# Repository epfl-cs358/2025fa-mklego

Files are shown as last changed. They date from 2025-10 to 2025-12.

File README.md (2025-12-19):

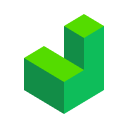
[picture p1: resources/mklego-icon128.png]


# CS-358 Project : MKLEGO 

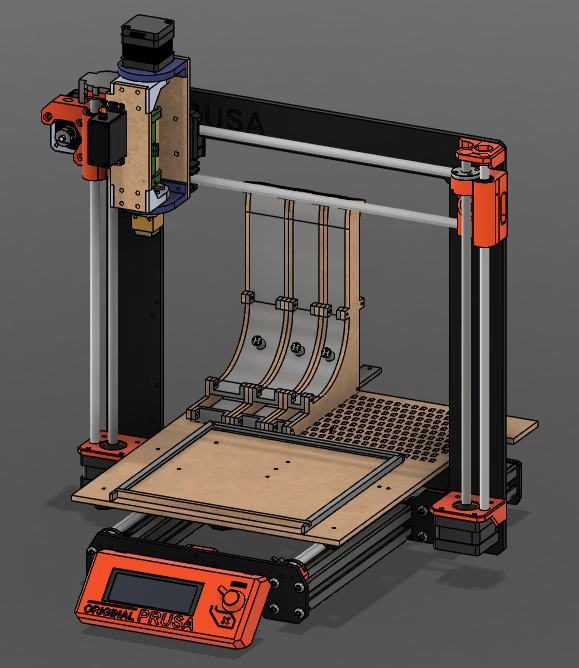
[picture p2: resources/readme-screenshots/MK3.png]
 

## Project overview

MKLEGO is a 3D printer that uses LEGO bricks to build any given structure layer by layer. The project is based on mofifying a PRUSA MK3 3D printer by 
- replacing the extruder with a custom nozzle that can pick, place and rotate LEGO bricks,
- changing the base plate to a LEGO compatible plate with place for custom LEGO brick dispensers,
- developing custom software to convert 3D models into LEGO brick instructions.

## Software
### How to run
Access the software repository here: [MKLEGO Software](/frontend/).
Run it by :
- From the `frontend` folder, run the project with 
   
   `./gradlew :desktop-app:run`.
- The application window should open. You can see your recent projects and open them if there are any.

Creating a new project :
- To create a new project, click on File > New File, then select an STL or lxfml file to load and slice a 3D model, or nothing to create a blank project.
- You can go back to the recent projects by clicking on File > Recent Projects.

Editing :
- Once you have opened a project, you can add, remove, or paint LEGO bricks.
- You can see the controls by pressing `H`.
- To paint an existing brick: select the targeted brick, then click on a color in the palette.
- Note: you can only place blocks on top of other blocks. You cannot add a floating brick

Supports :
- The translucid bricks are support bricks. They are added automatically underneath hanging bricks. You can also add some manually by using the gray color (rightmost) in the color palette. You can hide/show them by clicking on "Hide Supports" in the top right.

Printing :
- To export your LEGO project: open the desired project and go to File > Export as ... : use lgcode for human readable gcode, or LG for the binary file.
- To print your LEGO structure, export it as LG, store it in a SD card and transfer the file to the printer. Then, you can set the printer and launch the build through the printer's screen interface.
- You will be asked to show on the screen where your dispensers are placed and then the real printing will begin!

Screen Interface:
- Home Screen: you can select to either go to print or to settings
- Settings: Calibrate: Calibrate the x, y, z axis and the rotation (will automatically be done at the beginning of each print), Back: Get back to main menu (Home)
- Print menu: Press Files to choose a file to execute and Back to get back to Home. If on files choose which file to execute.
- File execution: If .TXT file the screen will play a music corresponding to the file. If .LG or .LGCODE file the model will be printed

### Pipeline
The JavaFX-based software pipeline includes:
- Loading a 3D model from an STL or lxfml (v5.0 Legacy LDD compatible) file,
- Slicing it into LEGO brick layers and assembling them in an optimal agencement,
- Rendering the LEGO structure in a 3D viewer to view and edit the build if needed,
- Generating the lgcode (custom g-code) instructions to be sent to the printer.

## Hardware architecture
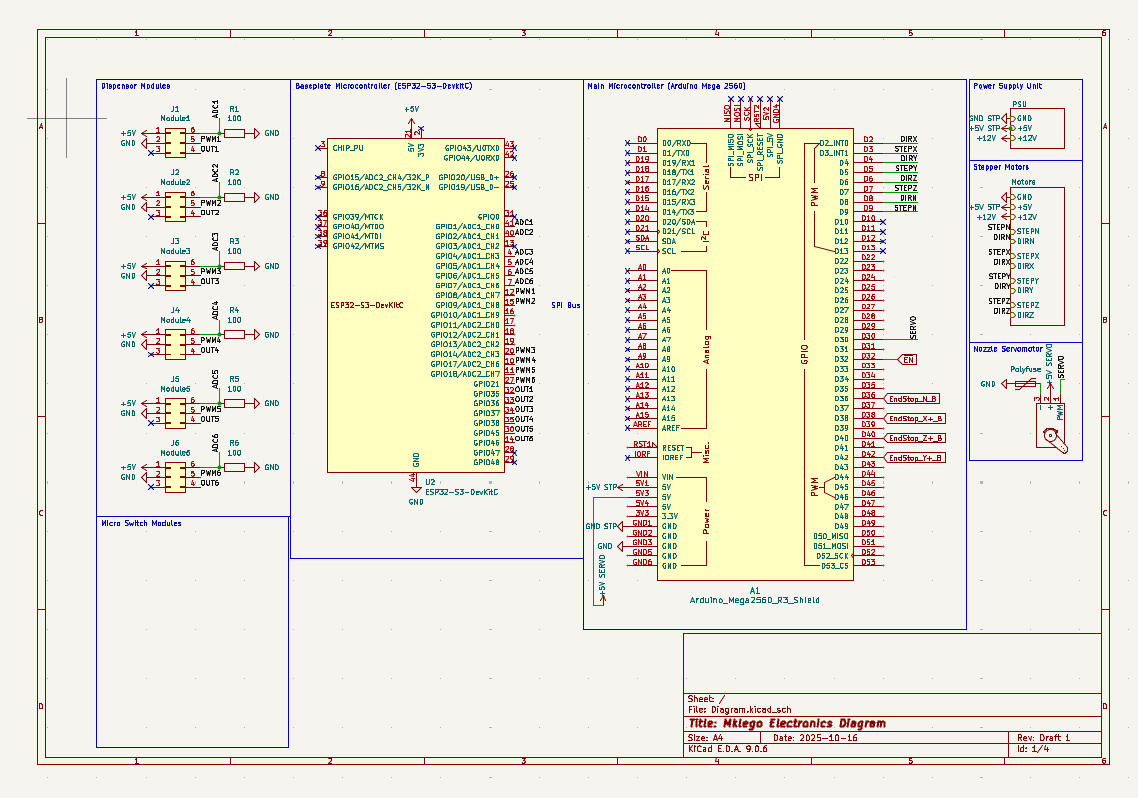
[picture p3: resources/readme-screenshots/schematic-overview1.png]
 
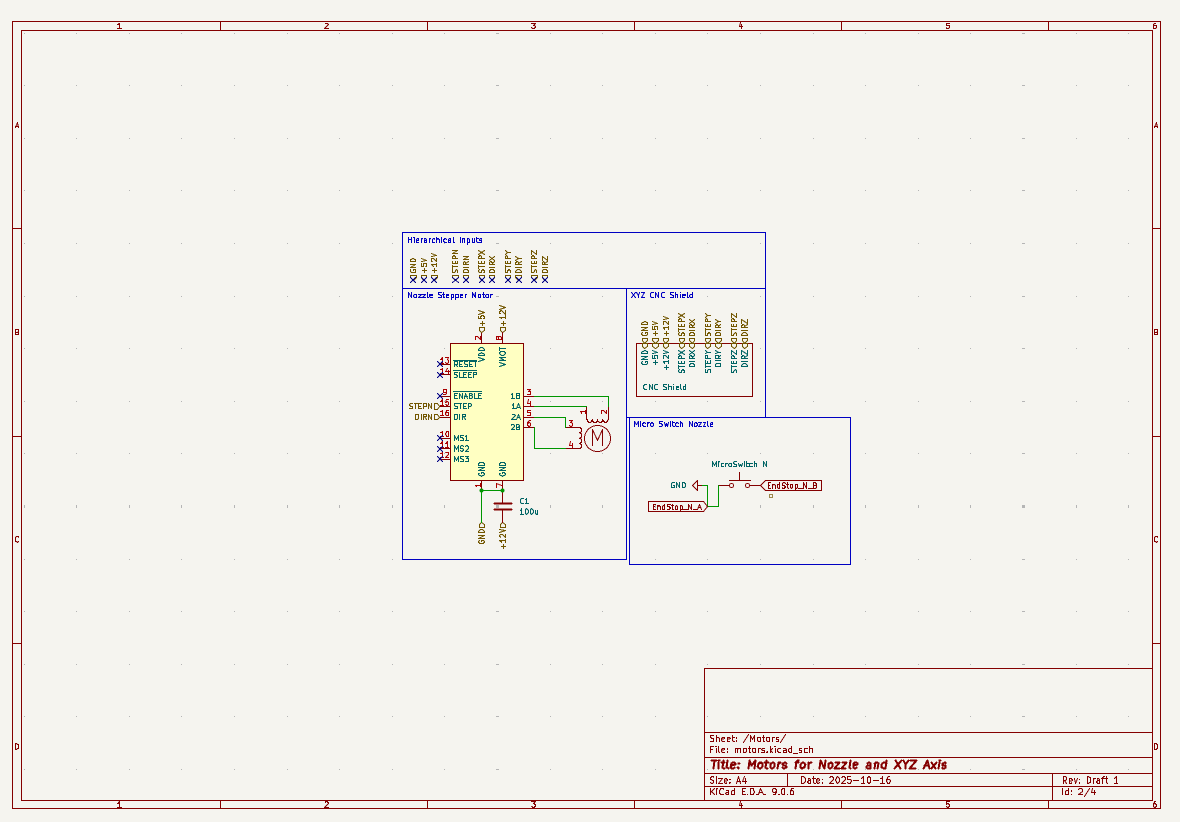
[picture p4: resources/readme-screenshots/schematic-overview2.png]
 
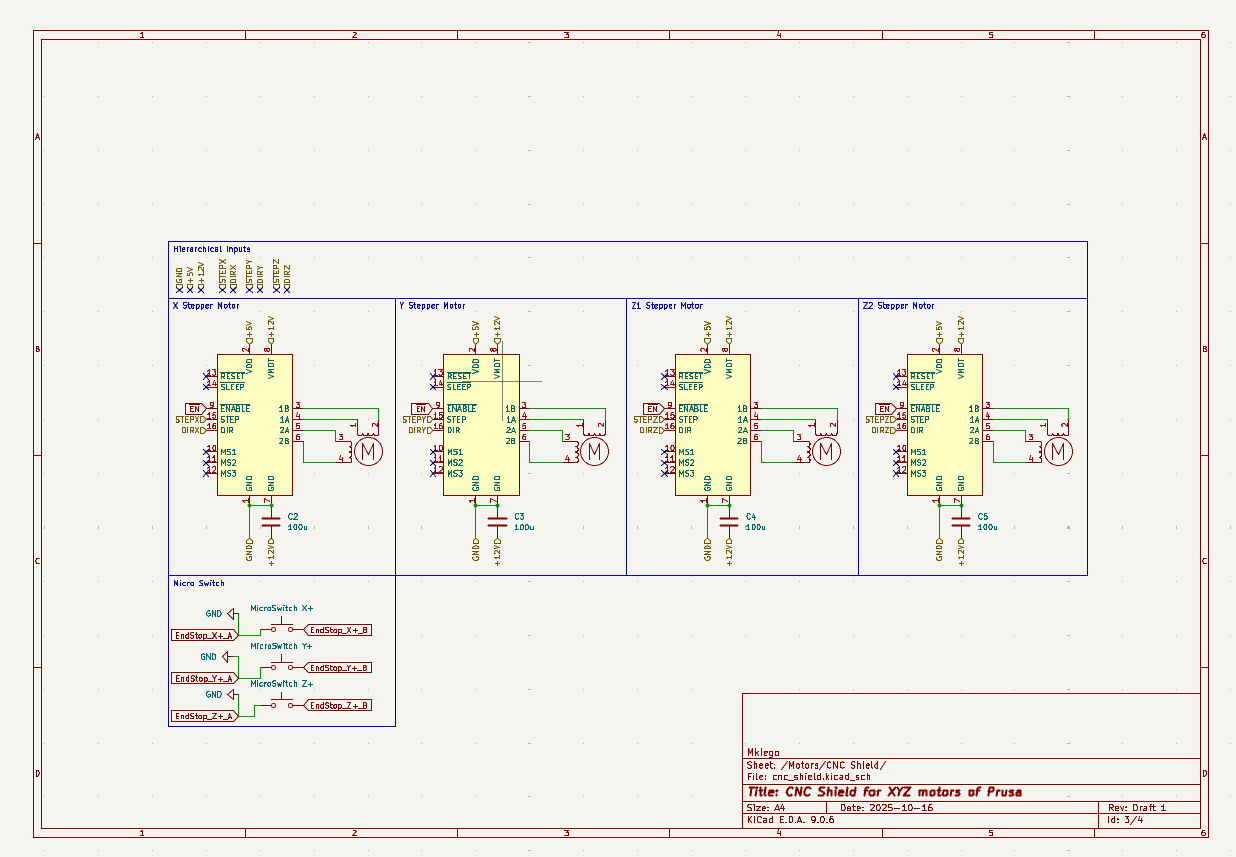
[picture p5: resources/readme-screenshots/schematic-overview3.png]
 

### Firmware
Access the firmware repository here: [MKLEGO Firmware](/embedded/mklego).

### System Overview

The hardware is organized around a **dual-microcontroller architecture**:

- **Main Controller**: Arduino Mega 
  Responsible for motion control (stepper motors), safety-critical timing, and real-time coordination.

- **Baseplate Controller**: ESP32-S3-DevKitC  
  Responsible for high-level logic, sensor acquisition, dispenser module control, and communication with the main controller.

The system integrates:
- Up to **8 LEGO dispenser modules**
- **3-axis stepper motor control (X, Y, Z)**
- A **servo motor** that pushes the brick down through the nozzle
- A centralized **power supply unit (PSU)** providing 5 V and 12 V rails

# Building Tutorial

This section explains how to physically build the MKLEGO prototype from a Prusa MK3 printer and the provided custom parts.  
All mechanical parts (DXF, STL and 3MF files) are available in the repository.

---

## Step 1: Preparation

### Required base machine
This prototype **requires a Prusa MK3 printer** as the mechanical base (frame, linear rails, motors).

### Disassembly
Before starting the build:

1. Power off and unplug the printer.
2. Remove the following components from the Prusa MK3:
   - Heated bed
   - Original extruder and hotend
   - Power Supply Unit (PSU)

⚠️ These components are **not used** in the MKLEGO system.

At the end of this step, you should keep:
- The printer frame
- X/Y/Z motion system
- Stepper motors

---

## Step 2: Mechanical Assembly Overview

The MKLEGO hardware is composed of three main subsystems:

1. **Custom LEGO Nozzle**
2. **LEGO-Compatible Base Plate**
3. **LEGO Brick Dispensers**

Each subsystem can be assembled independently before final integration on the printer.

---

## Nozzle Assembly

<p align="center">
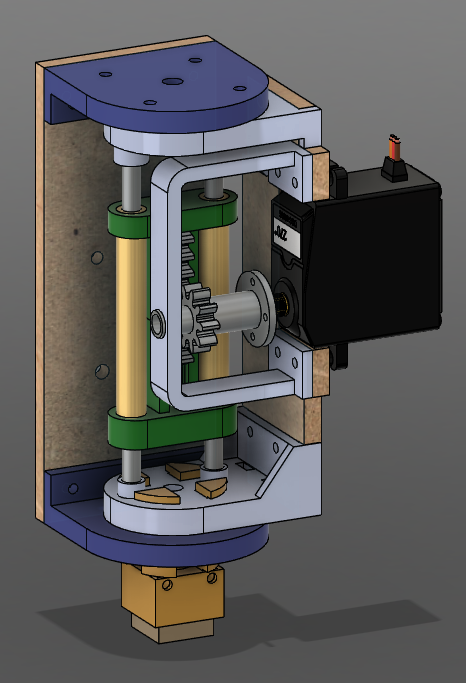
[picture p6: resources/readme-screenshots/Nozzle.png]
  
</p>
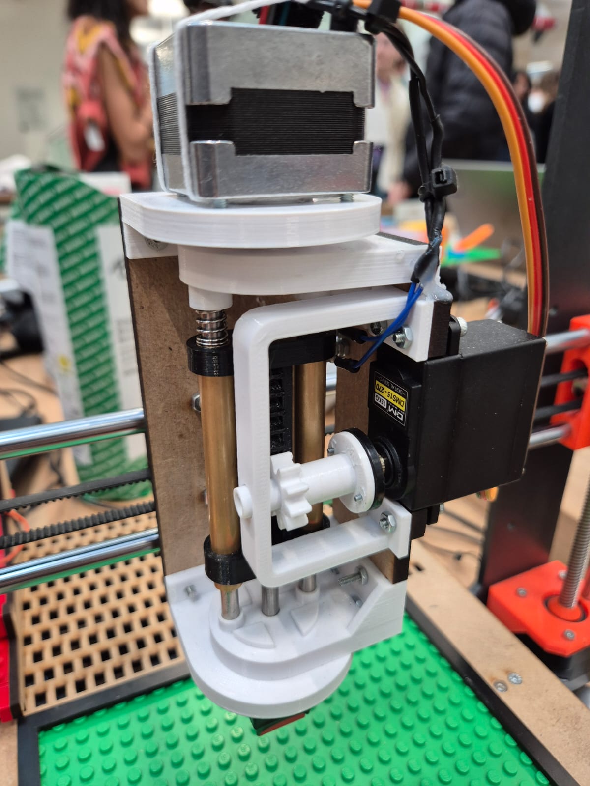
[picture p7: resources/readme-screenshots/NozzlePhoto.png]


### Notes
Primarily use M3 screws. M2.5 depending on the 3d files

---

### Materials

- [ ] 1 × NEMA 14 stepper motor  
- [ ] 1 × Servo motor (15 kg·cm recommended)  
- [ ] 2 × Brass hollow cylinders  
  - Outer diameter: 8 mm  
  - Inner diameter: 5 mm  
  - Length: 64 mm  
- [ ] 2 × Metal rods (97 mm long)  
- [ ] 3 × Springs (10 mm length)  
- [ ] 1 × Micro-switch  
- [ ] M3 and M2.5 screws and nuts  
- [ ] MDF parts (laser cut)  
- [ ] PETG parts (3D printed)

---

### Assembly Process

1. **Prepare the parts**
   - Find all the files in the resources/3D Models folder.
   - Laser cut all MDF components using the provided DXF files.
   - 3D print all plastic parts using the provided STL files (PETG).

3. **Linear structure**
   - Assemble all sliding components along the two metal rods.
   - Ensure smooth motion without excessive friction.

4. **Rotation mechanism**
   - Mount the servo motor.
   - Assemble the rotating LEGO-gripping section.
   - Don't forget the 2 springs: They go between the sliding part and the rotating part on the 2 outer rods.

5. **Final enclosure**
   - Add the fixed (non-rotating) outer structure.
   - Add the Lego grabber at the bottom. Don't forget the spring right above the grabber, on the rod.
   - Install the micro-switch for rotation calibration.

A fully assembled 3D model of the nozzle is available as a **3MF file** for reference.

### Notes:
Use M3 conical screws to connect the baseplate to the printer

---

## Base Plate Assembly

<p align="center">
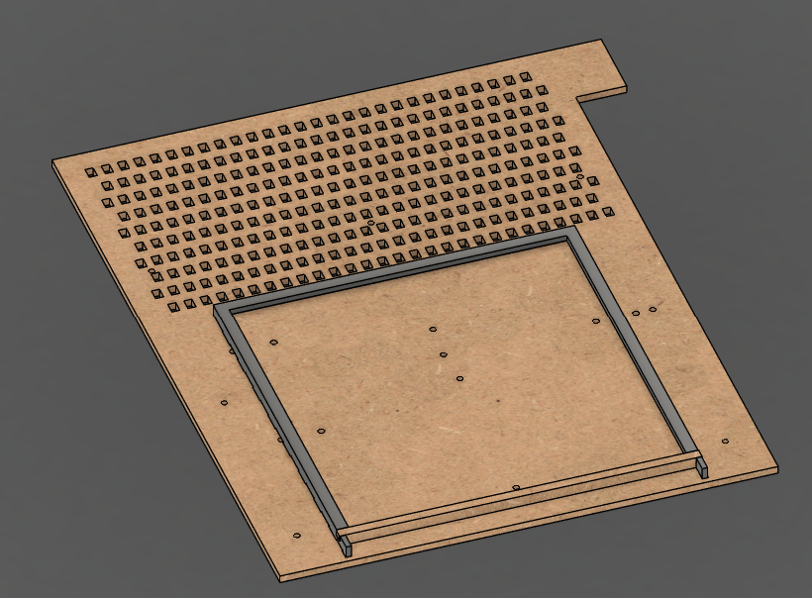
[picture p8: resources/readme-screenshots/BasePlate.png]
  
</p>

---

### Materials

- [ ] 1 × Micro-switch  
- [ ] MDF parts (laser cut)  
- [ ] PETG parts (3D printed)  
- [ ] 1 × LEGO base plate (22 × 22 studs)

---

### Assembly Process

1. Fabricate all MDF and PETG parts using the provided DXF and STL files in resources/3D Models/.
2. Assemble the mechanical structure of the base plate.
3. Install the micro-switch for Y-height referencing.
4. **You do not need mount the LEGO plate yet**

### Notes:
Use M3 conical screws to connect the dispensers as there needs to not be anything between them
do not add any screws to the middle screw holes of the dispensers
The path to lay the wires on the left side of the dispenser needs to be filed down to fit two wires 

A complete assembled model is also available as a **3MF file**.   

---

## Dispenser Assembly

<p align="center">
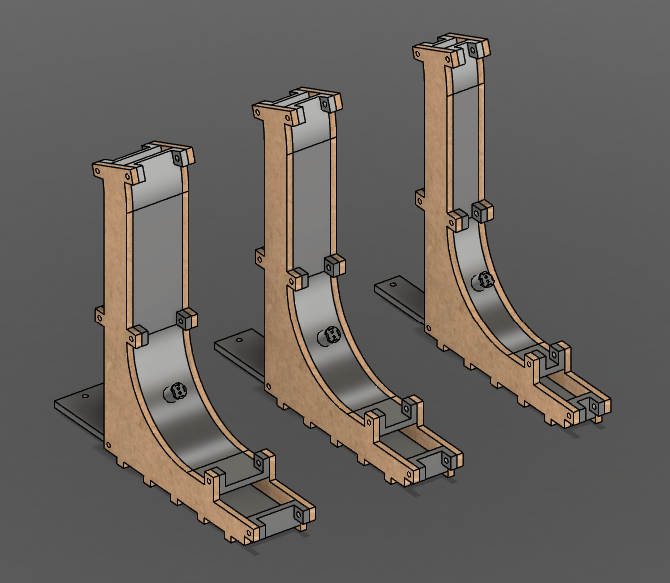
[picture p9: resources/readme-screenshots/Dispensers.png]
  
</p>

---

### Materials (per dispenser)

- [ ] 1 × IR LED  
- [ ] 1 × IR Receiver  
- [ ] M3 screws and nuts  
- [ ] MDF parts (laser cut)  
- [ ] PETG parts (3D printed)

---

### Assembly Process

1. Assemble the mechanical ramp structure. (Find all the files to make the parts in resources/3D Models/)
2. Install the IR LED and IR receiver:
   - Align them carefully to ensure reliable brick detection.
3. Test brick feeding manually before electronic integration.

A complete dispenser assembly is provided as a **3MF file**.

---
## Micro switches
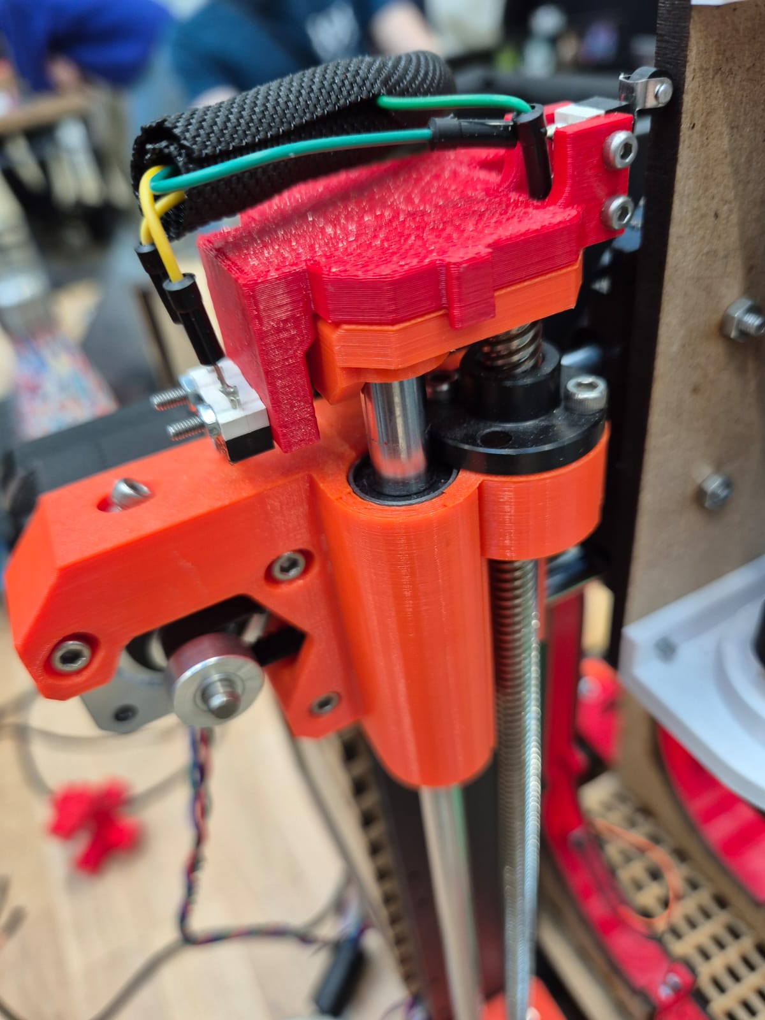
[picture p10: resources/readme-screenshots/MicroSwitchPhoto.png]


--- 

### Materials

- [ ] M2.5 screws and bolts
- [ ] 2 micro switches
- [ ] wires
- [ ] PETG parts (3D printed)

### Assembly Process
- Find the files in resources/3D Models
- Print the 3D structure
- Connect the wires into the main electrical box

---
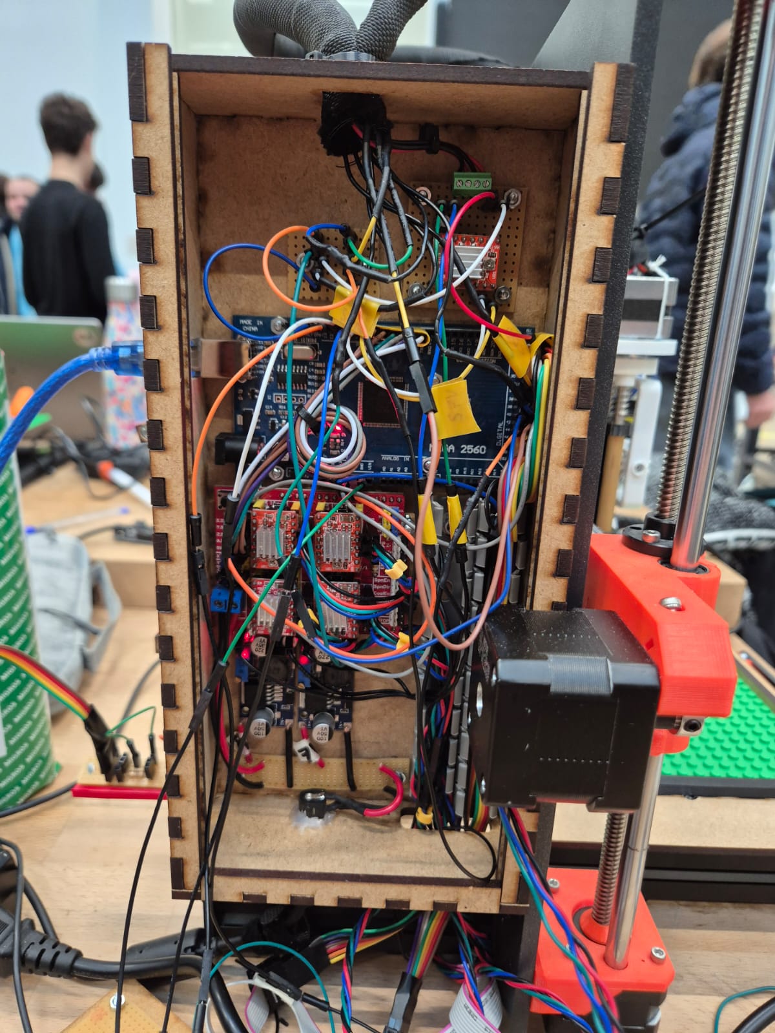
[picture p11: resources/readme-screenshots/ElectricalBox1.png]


### Main Electrical

---
### Materials
- [ ] 1 Arduino Mega
- [ ] 1 CNC shield with 4 motor drivers
- [ ] 1 motor driver
- [ ] 2 buck converters

### Setup instructions:
Arduino mega connects to the four motor drivers on the CNC shield
The four mk3 mothors are connected to the CNC shield
The motor driver is driving the Nema 14
Micro switches are connected to the Arduino Mega
Arduino controlls the servo motor (PWM pin)
Buck converter at 7V powers the Servo motor 
Buck converter at 8V powers the Nema 14
Barrel jack for the power supply at 12V powering the CNC shield and the buck converters
Arduino mega commmunicates with the ESP32(second electrical box) via a custom protocol found in the arduino code on the github
find the dxf files at resources/3D Models/Boxes/MDF_main_electrical_box.dxf

---
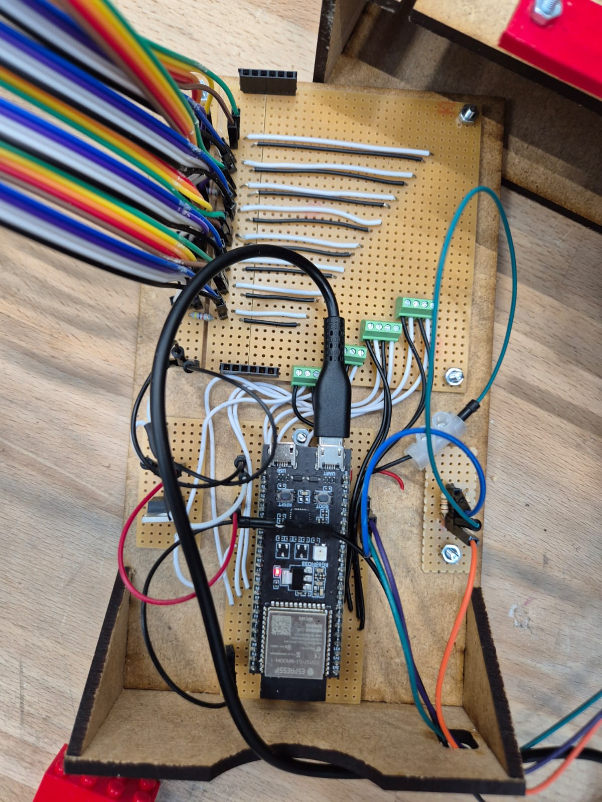
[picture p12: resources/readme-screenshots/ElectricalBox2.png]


### Secondary Electrical

---
### Materials
- [ ] 1 ESP32 S3 Dev Module
- [ ] 1 MOSFET 

### Setup instructions:
find the dxf files at: /resources/3D Models/Boxes/MDF_sub_electrical_box.dxf

### Notes:
This electrcial box connects to the dispensers
Connected by velcro to the printer body
The esp32 is connected to the dispensers and reads an adc input inside of a Voltage divider. Depending on the adc input we can deduce if a dispenser is connected, and which one it is, based on its internal resistance.

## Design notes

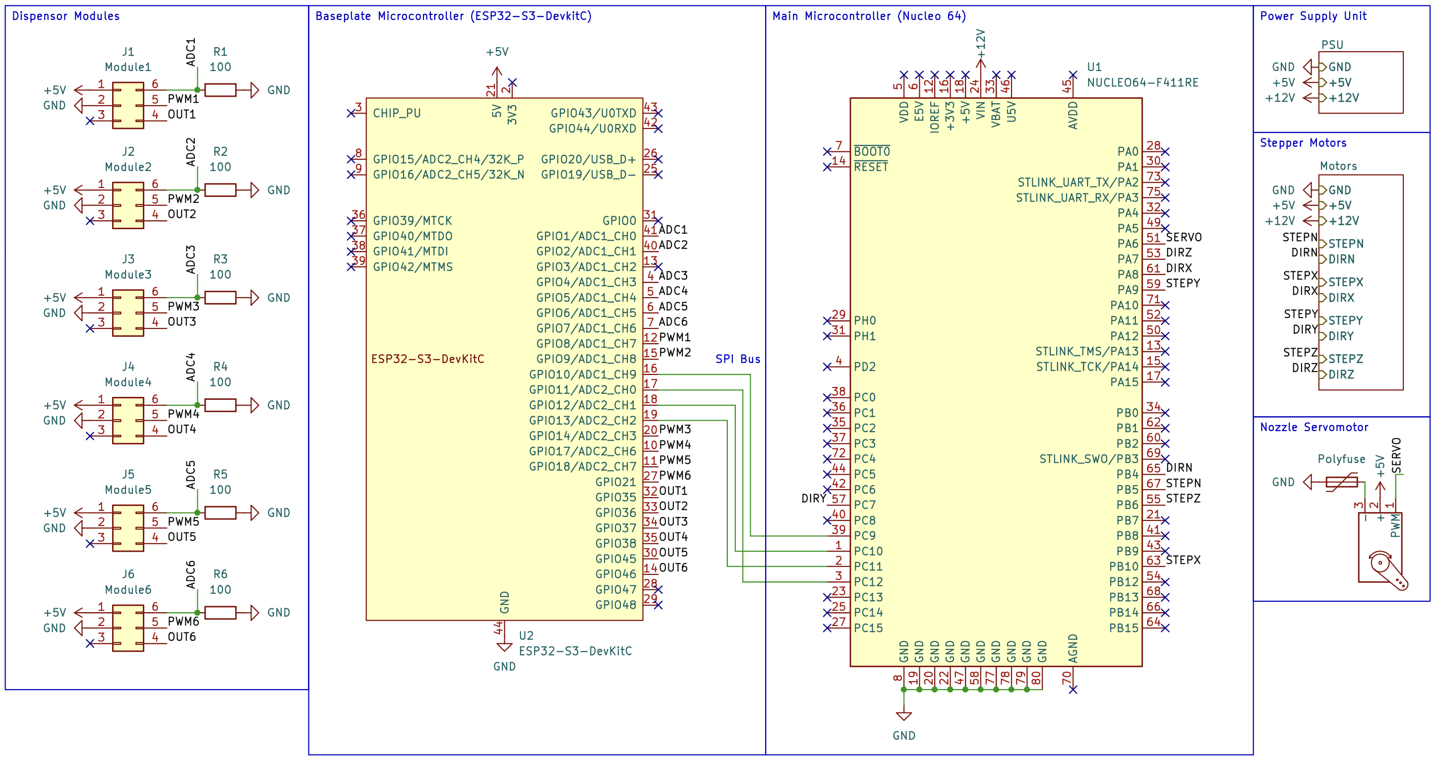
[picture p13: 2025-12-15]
resources/readme-screenshots/schematic-overview.png

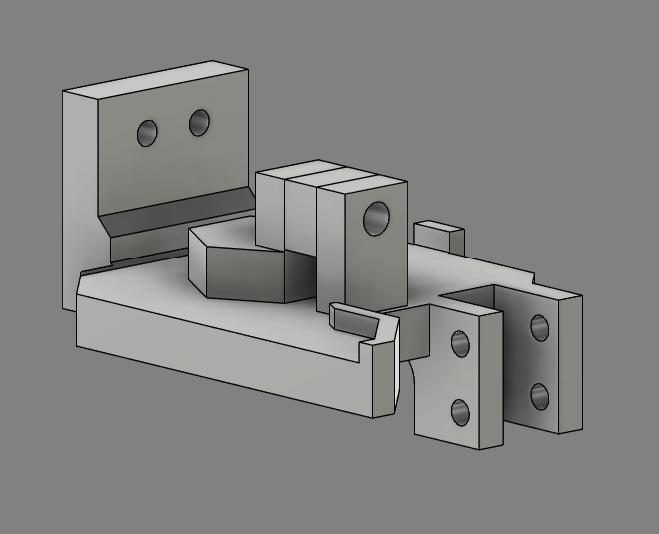
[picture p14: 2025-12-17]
resources/readme-screenshots/MicroSwitch.png

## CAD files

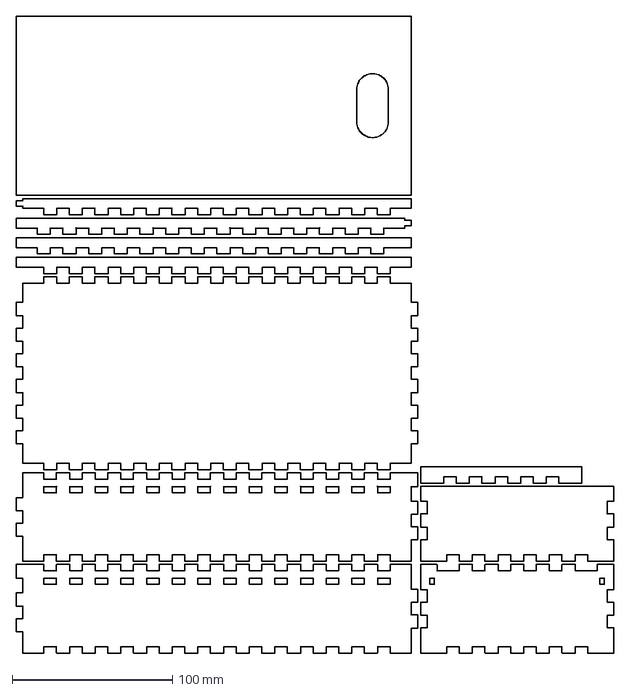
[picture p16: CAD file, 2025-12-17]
resources/3D Models/DXF/Boxes/MDF_main_electrical_box.dxf
372.4 x 397.2 mm

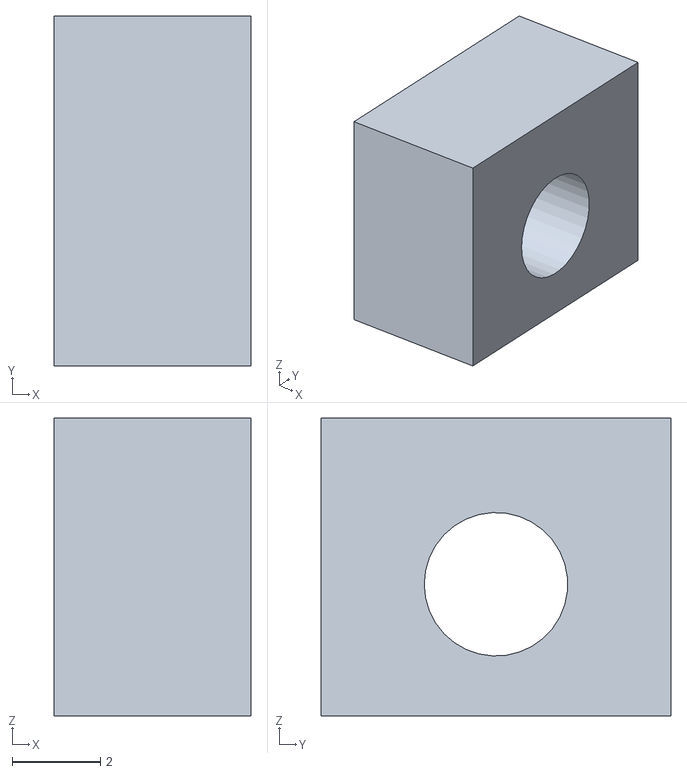
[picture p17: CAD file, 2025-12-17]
resources/3D Models/STL/MicroSwitch/MicroSwitch_Mk-Lego_Maintainer.stl
4.46 x 7.93 x 6.75

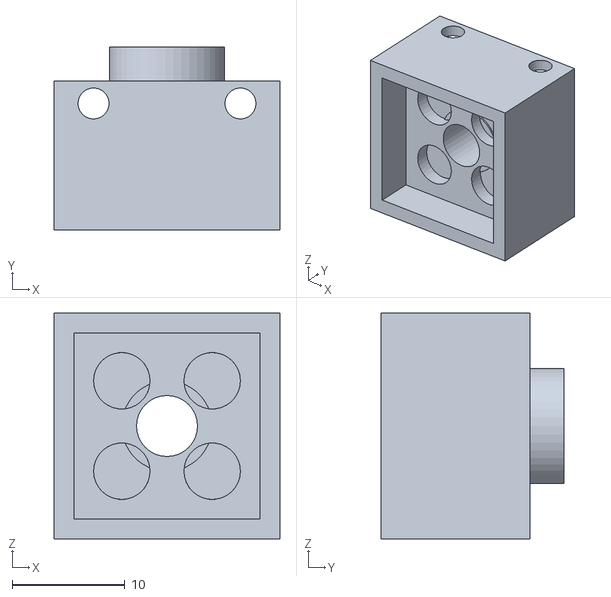
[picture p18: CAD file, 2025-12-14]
resources/3D Models/STL/Nozzle/Nozzle_Mk-Lego_Grabber_holder_main.stl
20.0 x 16.2 x 20.0

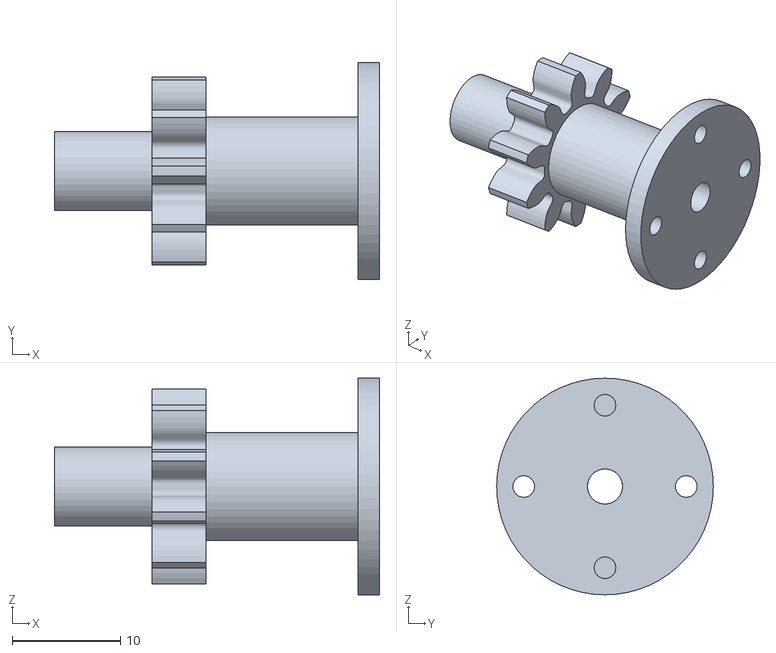
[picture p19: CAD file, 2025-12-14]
resources/3D Models/STL/Nozzle/Nozzle_Mk-Lego_Gear_main.stl
30.0 x 20.0 x 20.0

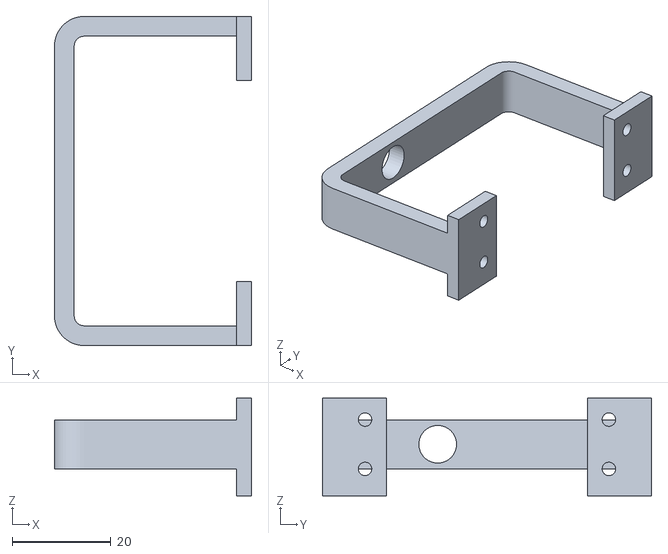
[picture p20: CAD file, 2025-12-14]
resources/3D Models/STL/Nozzle/Nozzle_Mk-Lego_Gear_holder_main.stl
40.0 x 66.8 x 19.8

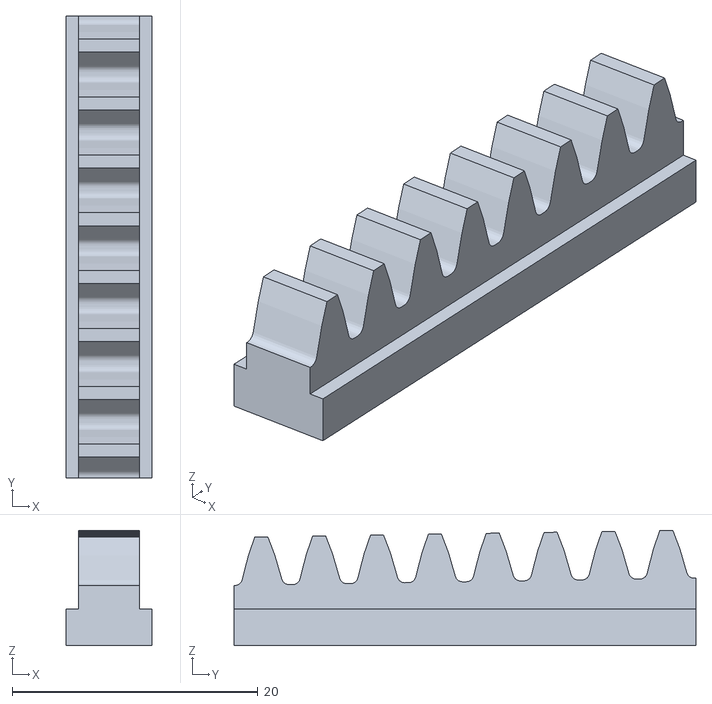
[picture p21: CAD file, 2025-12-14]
resources/3D Models/STL/Nozzle/Nozzle_Mk-Lego_Rack_main.stl
7.00 x 37.6 x 9.39

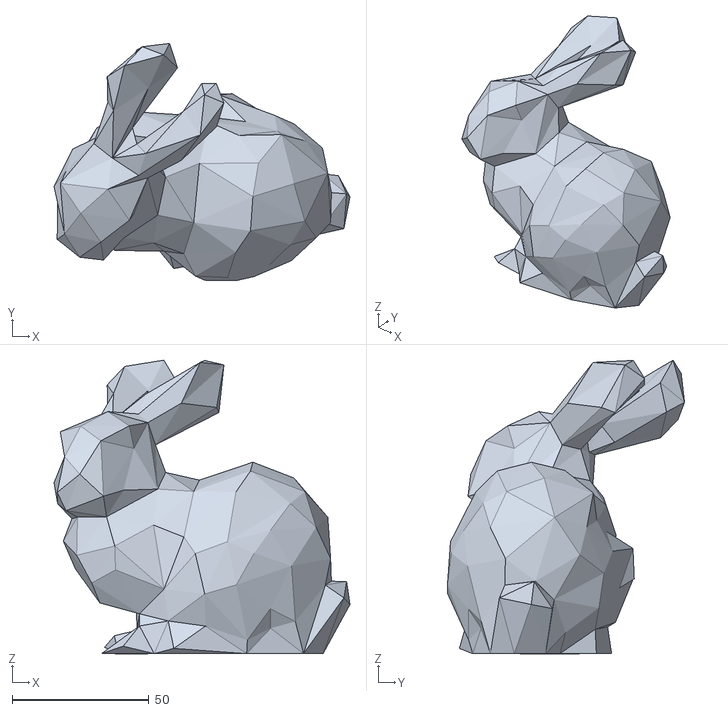
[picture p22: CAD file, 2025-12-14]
frontend/projects/desktop-app/Bunny-LowPoly.stl
108.1 x 86.6 x 107.3

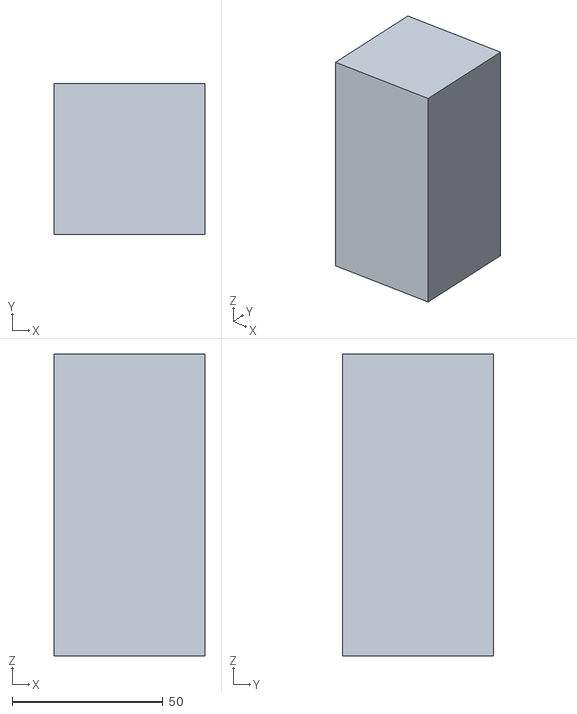
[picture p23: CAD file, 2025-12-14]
frontend/projects/obj-loader/src/test/resources/Cube.stl
50.0 x 50.0 x 100.0

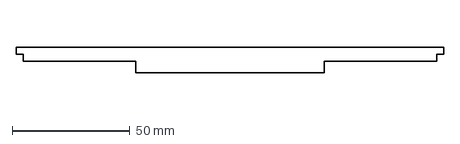
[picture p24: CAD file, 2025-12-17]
resources/3D Models/DXF/BasePlate/MDF_sliding_border.dxf
182.0 x 11.0 mm

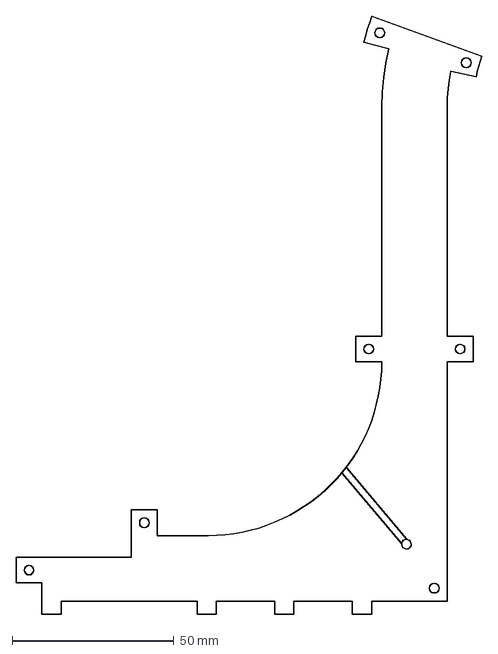
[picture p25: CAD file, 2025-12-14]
resources/3D Models/DXF/Dispensers/MDF_left_wall.dxf
144.2 x 185.0 mm

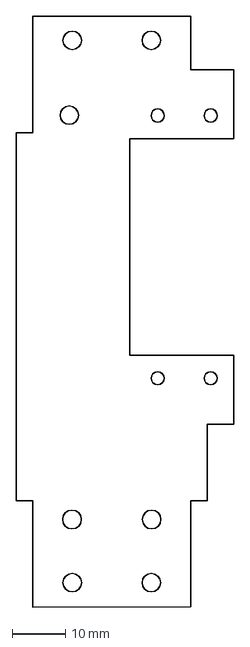
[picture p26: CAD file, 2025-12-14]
resources/3D Models/DXF/Nozzle/MDF_moving_holder.dxf
41.0 x 111.4 mm

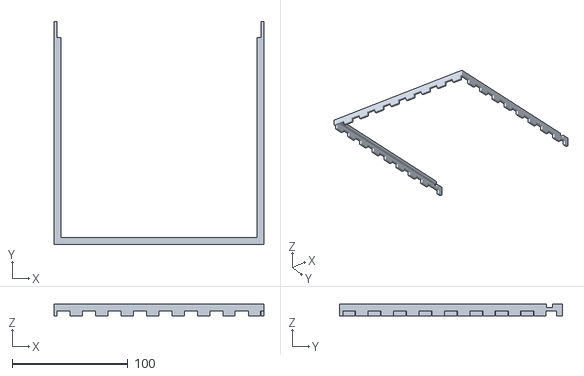
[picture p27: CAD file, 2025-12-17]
resources/3D Models/STL/BasePlate/BasePlate_Mk-Lego_Borders.stl
181.4 x 192.4 x 10.0

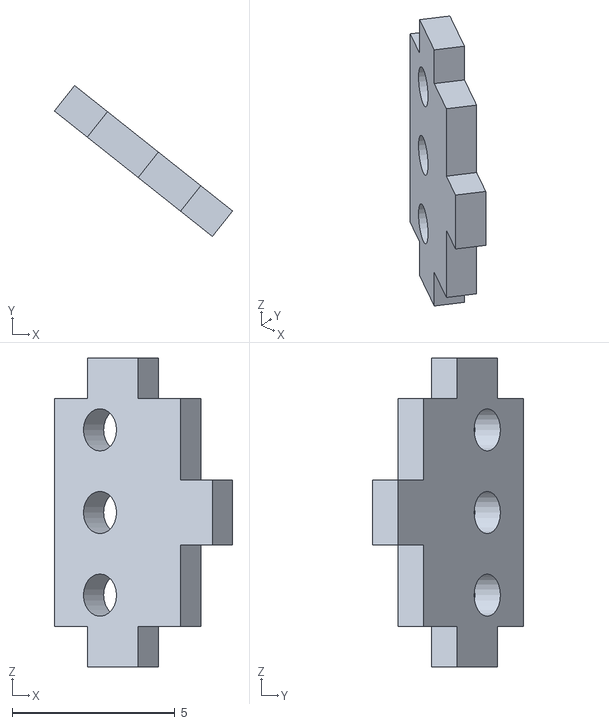
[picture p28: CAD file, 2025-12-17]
resources/3D Models/STL/Dispensers/Dispensers_Mk-Lego_IR_REC_Cap.stl
5.48 x 4.64 x 9.50

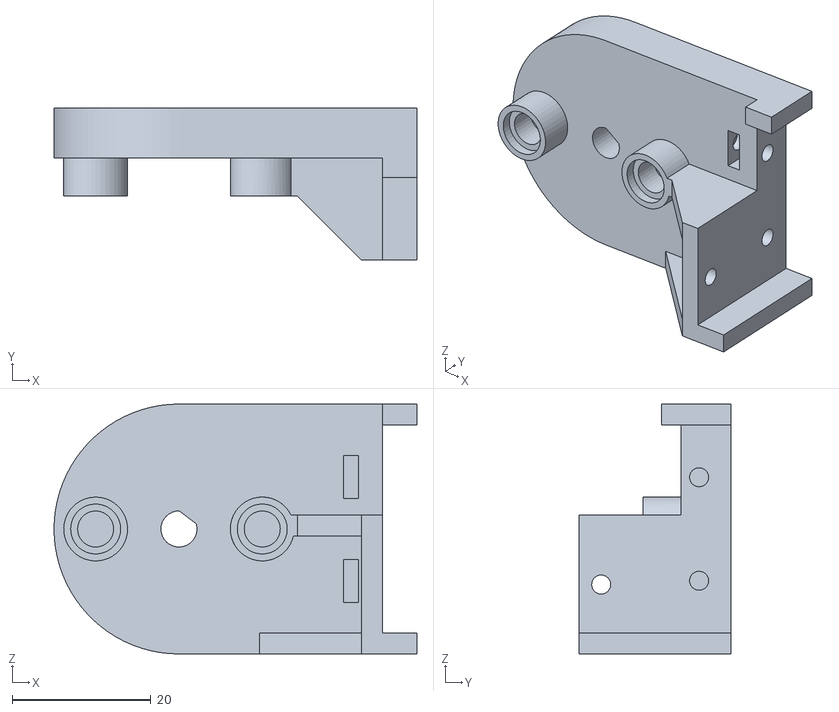
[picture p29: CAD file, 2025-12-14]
resources/3D Models/STL/Nozzle/Nozzle_Mk-Lego_Moving_holder_top.stl
52.3 x 21.9 x 36.0

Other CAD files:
frontend/projects/desktop-app/Large Box.stl
resources/3D Models/DXF/BasePlate/MDF_base_plate.dxf
resources/3D Models/DXF/Boxes/MDF_sub_electrical_box.dxf
resources/3D Models/DXF/Dispensers/MDF_right_wall.dxf
frontend/projects/desktop-app/Bunny-LowPoly-Big.stl
frontend/projects/desktop-app/LPcatBP.stl
resources/3D Models/BasePlate_Mk-Lego.f3d
resources/3D Models/DXF/Nozzle/MDF_fixed_holder.dxf
resources/3D Models/Dispensers_Mk-Lego.f3d
resources/3D Models/MicroSwitch_Mk-Lego.f3d
resources/3D Models/Nozzle_Mk-Lego.f3d
resources/3D Models/STL/Dispensers/Dispensers_Mk-Lego_Dispenser2x2_Ramp_BelowPart.stl
resources/3D Models/STL/Dispensers/Dispensers_Mk-Lego_Dispenser2x2_Ramp_UpperPart.stl
resources/3D Models/STL/Dispensers/Dispensers_Mk-Lego_Dispensers2x3_Ramp_BelowPart.stl
resources/3D Models/STL/Dispensers/Dispensers_Mk-Lego_Dispensers2x3_Ramp_UpperPart.stl
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

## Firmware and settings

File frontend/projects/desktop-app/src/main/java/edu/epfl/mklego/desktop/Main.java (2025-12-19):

package edu.epfl.mklego.desktop;

import java.util.AbstractMap.SimpleEntry;
import java.util.ArrayList;
import java.util.List;
import java.util.Map;
import java.util.Map.Entry;

import edu.epfl.mklego.desktop.alerts.AlertPane;
import edu.epfl.mklego.desktop.alerts.AlertQueue;
import edu.epfl.mklego.desktop.alerts.SimpleAlert;
import edu.epfl.mklego.desktop.alerts.SimpleAlert.AlertType;
import edu.epfl.mklego.desktop.home.ImportProjectForm;
import edu.epfl.mklego.desktop.home.RecentGrid;
import edu.epfl.mklego.desktop.home.model.RecentItem;
import edu.epfl.mklego.desktop.menubar.BorderlessScene;
import edu.epfl.mklego.desktop.menubar.MenubarIcon;
import edu.epfl.mklego.desktop.render.EditingController;
import edu.epfl.mklego.desktop.render.Scene3D;
import edu.epfl.mklego.desktop.utils.MappedList;
import edu.epfl.mklego.desktop.utils.Theme;
import edu.epfl.mklego.desktop.utils.form.ModalFormContainer;
import edu.epfl.mklego.lgcode.LGCode;
import edu.epfl.mklego.lgcode.ProjectConverter;
import edu.epfl.mklego.lgcode.format.Serializable;
import edu.epfl.mklego.project.Project;
import edu.epfl.mklego.project.ProjectException;
import edu.epfl.mklego.project.ProjectManager;
import edu.epfl.mklego.project.scene.entities.LegoPiece.StdLegoPieceKind;
import javafx.application.Application;
import javafx.collections.ObservableList;
import javafx.event.ActionEvent;
import javafx.geometry.Insets;
import javafx.geometry.Pos;
import javafx.scene.Node;
import javafx.scene.control.Button;
import javafx.scene.control.CheckMenuItem;
import javafx.scene.control.Menu;
import javafx.scene.control.MenuBar;
import javafx.scene.control.MenuItem;
import javafx.scene.control.RadioMenuItem;
import javafx.scene.control.SeparatorMenuItem;
import javafx.scene.control.ToggleButton;
import javafx.scene.control.ToggleGroup;
import javafx.scene.effect.DropShadow;
import javafx.scene.effect.Effect;
import javafx.scene.effect.Glow;
import javafx.scene.effect.SepiaTone;
import javafx.scene.image.Image;
import javafx.scene.input.KeyCode;
import javafx.scene.input.KeyCombination;
import javafx.scene.layout.HBox;
import javafx.scene.layout.StackPane;
import javafx.scene.layout.VBox;
import javafx.scene.paint.Color;
import javafx.stage.FileChooser;
import javafx.stage.Stage;
import javafx.stage.StageStyle;
import jfxtras.styles.jmetro.Style;

import java.io.ByteArrayOutputStream;
import java.io.File;
import java.io.FileNotFoundException;
import java.io.FileOutputStream;
import java.io.IOException;
import java.io.OutputStream;
import java.nio.file.Path;


public class Main extends Application {

    private ProjectManager projectManager;
    private StackPane totalPane;
    private RecentGrid recentGrid;
    private Project currentProject;
    // colorId -> (name, resistance)
    private final java.util.Map<Integer, Entry<String, String>> colorConfig = new java.util.HashMap<>();


    private static final String BTN_NORMAL =
    "-fx-background-radius: 3px;" +
    "-fx-background-insets: 0;" +
    "-fx-padding: 0;";

private static final String BTN_SELECTED =
    "-fx-background-radius: 3px;" +
    "-fx-background-insets: 0;" +
    "-fx-padding: 0;" +
    "-fx-border-color: white;" +
    "-fx-border-width: 2px;" +
    "-fx-border-radius: 3px;";


    private static CheckMenuItem createMenuItem (String title){
        CheckMenuItem cmi = new CheckMenuItem(title);
        cmi.setSelected(true);
        return cmi;
    }

    @SuppressWarnings("unchecked")
    private final Entry<String, Effect>[] effects = new Entry[] {
        new SimpleEntry<String, Effect>("Sepia Tone", new SepiaTone()),
        new SimpleEntry<String, Effect>("Glow", new Glow()),
        new SimpleEntry<String, Effect>("Shadow", new DropShadow())
    };

    public MenuBar exampleMenuBar (Node img) {
        MenuBar menuBar = new MenuBar();

        // --- Menu File
        Menu menuFile = new Menu("File");

        MenuItem newFile = new MenuItem("New Project");
        newFile.setOnAction((ActionEvent t) -> {
                ModalFormContainer.getInstance().setForm(
                    new ImportProjectForm(
                        (Stage) menuBar.getScene().getWindow(),
                        projectManager));
        });

        MenuItem backToRecent = new MenuItem("Recent Projects");
        backToRecent.setOnAction(e ->
            showRecentGrid(totalPane, recentGrid)
        );

        MenuItem exportGcode = new MenuItem("Export as lgcode (text) ...");
        exportGcode.setOnAction(e -> {
            try {
                if (currentProject == null) return;
                // ask user where to save
                FileChooser fileChooser = new FileChooser();
                fileChooser.setTitle("Export LGCode");
                fileChooser.getExtensionFilters().add(
                    new FileChooser.ExtensionFilter("LGCode files (*.lgcode)", "*.lgcode")
                );
                fileChooser.setInitialFileName("project");

                File file = fileChooser.showSaveDialog(
                    menuBar.getScene().getWindow()
                );

                if (file == null) {
                    return; // user cancelled
                }

                // generate LGCode from project
                LGCode lgcode = ProjectConverter.createCode(currentProject);
                //lgcode = applyColorConfig(lgcode, colorConfig);

                // write text data to file
                try (FileOutputStream fos = new FileOutputStream(file)) {
                    lgcode.writeText(fos);
                }

            } catch (IOException ex) {
                ex.printStackTrace();
            }
        });


        Menu export = new Menu("Export as");
        MenuItem exportLG = new MenuItem("Export as LG (binary) ...");
        exportLG.setOnAction(e -> {
            try {
                if (currentProject == null) return;
                // ask user where to save
                FileChooser fileChooser = new FileChooser();
                fileChooser.setTitle("Export LG");
                fileChooser.getExtensionFilters().add(
                    new FileChooser.ExtensionFilter("LG files (*.LG)", "*.LG")
                );
                fileChooser.setInitialFileName("project");

                File file = fileChooser.showSaveDialog(
                    menuBar.getScene().getWindow()
                );

                if (file == null) {
                    return; // user cancelled
                }

                // generate LG from project
                LGCode lg = ProjectConverter.createCode(currentProject);
                //lg = applyColorConfig(lg, colorConfig);


                // write binary data to file
                try (FileOutputStream fos = new FileOutputStream(file)) {
                    lg.writeBinary(fos);
                }

            } catch (IOException ex) {
                ex.printStackTrace();
            }
        });


        MenuItem exit = new MenuItem("Exit");
        exit.setOnAction((ActionEvent t) -> System.exit(0));
        export.getItems().addAll(exportGcode, exportLG);
        menuFile.getItems().addAll(
            newFile,
            backToRecent,
            export,
            new SeparatorMenuItem(),
            exit
        );

        // --- Menu Edit
        Menu menuEdit = new Menu("Edit");
        Menu menuEffect = new Menu("Picture Effect");

        final ToggleGroup groupEffect = new ToggleGroup();
        for (Entry<String, Effect> effect : effects) {
            RadioMenuItem itemEffect = new RadioMenuItem(effect.getKey());
            itemEffect.setUserData(effect.getValue());
            itemEffect.setToggleGroup(groupEffect);
            menuEffect.getItems().add(itemEffect);
        }

        final MenuItem noEffects = new MenuItem("No Effects");
        noEffects.setDisable(true);

        menuEdit.getItems().addAll(menuEffect, noEffects);

        // --- Menu View
        Menu menuView = new Menu("View");
        CheckMenuItem titleView = createMenuItem("Title");
        CheckMenuItem binNameView = createMenuItem("Binomial name");
        CheckMenuItem picView = createMenuItem("Picture");
        CheckMenuItem descriptionView = createMenuItem("Decsription");
        menuView.getItems().addAll(titleView, binNameView, picView, descriptionView);

        menuBar.getMenus().addAll(menuFile, menuEdit, menuView);
        return menuBar;
    }

    @Override
    public void start(Stage stage) throws ProjectException, FileNotFoundException {
        stage.initStyle(StageStyle.UNDECORATED);
        Theme theme = Theme.getTheme();
        theme.setStyle(Style.DARK);

        Image iconImage = new Image(
            this.getClass().getResource("mklego-icon128.png").toExternalForm());
        stage.getIcons().add(iconImage);
        stage.setTitle("MKLego - Desktop App");

        // --- Create RecentGrid Example ---
        Path rootPath = Path.of("mklego-save-projects");
        this.projectManager = new ProjectManager(rootPath);

        ObservableList<RecentItem> recentItems = new MappedList<>(
            this.projectManager.projectsProperty(),
            project -> new RecentItem(theme, project));

        AlertQueue queue = new AlertQueue();
        this.totalPane = new StackPane();
        
        EditingController editing = new EditingController();

        BorderlessScene scene = new BorderlessScene(queue, stage, theme, totalPane, 640, 480);

        this.recentGrid = new RecentGrid(recentItems, project -> {
            try {
                this.currentProject = project;
                queue.pushBack(new SimpleAlert(AlertType.INFO, "Opening " + project.getName())
                    .withSource("RecentGrid"));

                LGCode code = ProjectConverter.createCode(project);
                ByteArrayOutputStream outputStream = new ByteArrayOutputStream();
                code.writeText(outputStream);

                Scene3D scene3d = new Scene3D(theme, project.getScene(), 0, 0);
                editing.control(scene3d);
                scene3d.bindSizeToContainer(totalPane);


        // === COLOR PALETTE UI (compact & fixed size) ====================
        HBox colorPanel = new HBox(4);
        colorPanel.setStyle(
            "-fx-background-color: rgba(20,20,20,0.9);" +
            "-fx-padding: 4px;" +
            "-fx-background-radius: 6px;"
        );
        


        Color[] colors = {
            Color.RED,
            Color.DEEPSKYBLUE,
            Color.YELLOW,
            Color.GREEN,
            Color.ORANGE,
            Color.PURPLE,
            Color.WHITE,
            Color.BLACK,
            Color.color(0.5, 0.5, 0.5, 0.3) // TRANSPARENT SUPPORT
        };
        final javafx.scene.control.Button[] selectedColorButton = new javafx.scene.control.Button[1];
        for (Color c : colors) {
            Button b = new Button();
            b.setPrefSize(20, 20);
            b.setMinSize(20, 20);
            b.setMaxSize(20, 20);
            b.setFocusTraversable(false);
            b.setStyle(
                BTN_NORMAL +
                "-fx-background-color: rgb("
                    + (int)(c.getRed() * 255) + ","
                    + (int)(c.getGreen() * 255) + ","
                    + (int)(c.getBlue() * 255) + ");"
            );

            b.setOnAction(e -> {
                // Update editor
                editing.setCurrentColor(c);

                // Unselect previous
                if (selectedColorButton[0] != null) {
                    selectedColorButton[0].setStyle(
                        BTN_NORMAL +
                        selectedColorButton[0].getStyle() 
                            .replace(BTN_SELECTED, "")
                    );
                }

                // Select this one
                b.setStyle(
                    BTN_SELECTED +
                    "-fx-background-color: rgb("
                        + (int)(c.getRed() * 255) + ","
                        + (int)(c.getGreen() * 255) + ","
                        + (int)(c.getBlue() * 255) + ");"
                );

                selectedColorButton[0] = b;
            });

            colorPanel.getChildren().add(b);
        }
        // Preselect default color (first one, or match currentAddColor)
        if (!colorPanel.getChildren().isEmpty()) {
            Button defaultBtn = (Button) colorPanel.getChildren().get(0);

            // Apply selected style
            defaultBtn.setStyle(
                BTN_SELECTED +
                defaultBtn.getStyle().replace(BTN_NORMAL, "")
            );

            selectedColorButton[0] = defaultBtn;
        }



        //prevent StackPane stretching
        colorPanel.setMaxSize(StackPane.USE_PREF_SIZE, StackPane.USE_PREF_SIZE);
        colorPanel.setPrefSize(StackPane.USE_COMPUTED_SIZE, StackPane.USE_COMPUTED_SIZE);
        colorPanel.setPickOnBounds(false);

        // Position in corner
        StackPane.setAlignment(colorPanel, Pos.TOP_RIGHT);
        StackPane.setMargin(colorPanel, new Insets(12));

        // Start hidden
        colorPanel.setVisible(true);




        // === SIZE PALETTE UI (ADD MODE) ================================
        HBox sizePanel = new HBox(4);
        sizePanel.setStyle(
            "-fx-background-color: rgba(20,20,20,0.9);" +
            "-fx-padding: 4px;" +
            "-fx-background-radius: 6px;"
        );

        // LEGO sizes (rows × columns)
        StdLegoPieceKind[] sizes = {
            new StdLegoPieceKind(2, 2),
            new StdLegoPieceKind(2, 3),
            new StdLegoPieceKind(2, 4),
        };

        // Track selected size button (same pattern as color)
        final Button[] selectedSizeButton = new Button[1];

        for (StdLegoPieceKind kind : sizes) {
            Button b = new Button(
                kind.getNumberRows() + "×" + kind.getNumberColumns()
            );

            b.setFocusTraversable(false);
            b.setStyle(
                BTN_NORMAL +
                "-fx-font-size: 11px;" +
                "-fx-padding: 2 6 2 6;" +
                "-fx-background-radius: 4px;"
            );

            b.setOnAction(e -> {
                editing.setCurrentAddKind(kind);

                if (selectedSizeButton[0] != null) {
                    selectedSizeButton[0].setStyle(
                        BTN_NORMAL +
                        "-fx-font-size: 11px;" +
                        "-fx-padding: 2 6 2 6;" +
                        "-fx-background-radius: 4px;"
                    );
                }

                b.setStyle(
                    BTN_SELECTED +
                    "-fx-border-color: #ffffffff;" +
                    "-fx-font-size: 11px;" +
                    "-fx-padding: 2 6 2 6;" +
                    "-fx-background-radius: 4px;"
                );

                selectedSizeButton[0] = b;
            });

            // 🔵 PRESELECT DEFAULT SIZE (2×4)
            if (kind.getNumberRows() == 2 && kind.getNumberColumns() == 4) {
                b.setStyle(
                    BTN_SELECTED +
                    "-fx-border-color: #ffffffff;" +
                    "-fx-font-size: 11px;" +
                    "-fx-padding: 2 6 2 6;" +
                    "-fx-background-radius: 4px;"
                );
                selectedSizeButton[0] = b;
            }

            sizePanel.getChildren().add(b);
        }


        // Prevent StackPane stretching
        sizePanel.setMaxSize(StackPane.USE_PREF_SIZE, StackPane.USE_PREF_SIZE);
        sizePanel.setPrefSize(StackPane.USE_COMPUTED_SIZE, StackPane.USE_COMPUTED_SIZE);
        sizePanel.setPickOnBounds(false);

        // Position below color panel
        StackPane.setAlignment(sizePanel, Pos.TOP_RIGHT);
        StackPane.setMargin(sizePanel, new Insets(44, 12, 12, 12));

        // Start visible (or control via mode if you want)
        sizePanel.setVisible(true);




        // === SUPPORT PIECES TOGGLE ================================

        String SUPPORT_TOGGLE_OFF =
            "-fx-background-radius: 4px;" +
            "-fx-background-insets: 0;" +
            "-fx-padding: 2 6 2 6;" +
            "-fx-font-size: 11px;" +
            "-fx-background-color: #3a3a3a;" +
            "-fx-text-fill: white;";

        String SUPPORT_TOGGLE_ON =
            "-fx-background-radius: 4px;" +
            "-fx-background-insets: 0;" +
            "-fx-padding: 2 6 2 6;" +
            "-fx-font-size: 11px;" +
            "-fx-background-color: #2196f3;" +
            "-fx-text-fill: white;";



        ToggleButton supportToggle = new ToggleButton("Hide Supports");
        supportToggle.setFocusTraversable(false);
        supportToggle.setSelected(false); // false = supports visible

        supportToggle.setStyle(SUPPORT_TOGGLE_OFF);

        supportToggle.selectedProperty().addListener((obs, oldV, selected) -> {
            // selected = hide supports
            scene3d.setSupportPiecesVisible(!selected);

            supportToggle.setStyle(
                selected ? SUPPORT_TOGGLE_ON : SUPPORT_TOGGLE_OFF
            );
        });


        supportToggle.setOnMouseEntered(e ->
            supportToggle.setOpacity(0.85)
        );
        supportToggle.setOnMouseExited(e ->
            supportToggle.setOpacity(1.0)
        );

        VBox sizeAndSupportPanel = new VBox(6);
        sizeAndSupportPanel.setAlignment(Pos.TOP_RIGHT);
        sizeAndSupportPanel.getChildren().addAll(sizePanel, supportToggle);

        sizeAndSupportPanel.setMaxSize(StackPane.USE_PREF_SIZE, StackPane.USE_PREF_SIZE);
        sizeAndSupportPanel.setPickOnBounds(false);

        StackPane.setAlignment(sizeAndSupportPanel, Pos.TOP_RIGHT);
        StackPane.setMargin(sizeAndSupportPanel, new Insets(44, 12, 12, 12));





                // === HELP OVERLAY =============================================
                queue.pushBack(new SimpleAlert(AlertType.INFO, "PRESS H FOR HELP")
                    .withSource("EditingController"));
                StackPane helpOverlay = new StackPane();
                helpOverlay.setStyle(
                    "-fx-background-color: rgba(0,0,0,0.75);" +
                    "-fx-padding: 40px;");
                helpOverlay.setVisible(false);

                var helpText = new javafx.scene.control.Label(
                    """
                    Controls
                    -----------------------------------------
                    Camera:
                    • O – Orbit mode
                    • P – Pan mode
                    
                    Editing:
                    • S – Select mode
                    • D – Delete mode
                    • A – Add mode
                    • R – Rotate preview brick
                    
                    Misc:
                    • ESC – Exit current mode
                    • H – Toggle help panel
                    """
                );
                helpText.setStyle(
                    "-fx-font-size: 18px;" +
                    "-fx-text-fill: white;" +
                    "-fx-font-family: 'Consolas';");

                helpOverlay.getChildren().add(helpText);
                showEditor(
                    totalPane,
                    scene3d,
                    colorPanel,
                    sizeAndSupportPanel,
                    helpOverlay
                );


                // === KEY HANDLERS ============================================
                scene.setOnKeyPressed(event -> {
                    if (event.getCode() == KeyCode.H) {
                        helpOverlay.setVisible(!helpOverlay.isVisible());
                    }

                    else if (event.getCode() == KeyCode.ESCAPE) {
                        helpOverlay.setVisible(false);
                        scene3d.getCameraController().getPanController().setEnabled(false);
                        scene3d.getCameraController().getOrbitController().setEnabled(false);
                        editing.setEnabled(false);
                        editing.setMode(EditingController.Mode.SELECT);

                    }

                    else if (event.getCode() == KeyCode.O) {
                        helpOverlay.setVisible(false);
                        scene3d.getCameraController().getPanController().setEnabled(false);
                        scene3d.getCameraController().getOrbitController().setEnabled(true);
                        editing.setEnabled(false);
                        editing.setMode(EditingController.Mode.SELECT);

                    }

                    else if (event.getCode() == KeyCode.P) {
                        helpOverlay.setVisible(false);
                        scene3d.getCameraController().getOrbitController().setEnabled(false);
                        scene3d.getCameraController().getPanController().setEnabled(true);
                        editing.setEnabled(false);
                        editing.setMode(EditingController.Mode.SELECT);
                    }

                    else if (event.getCode() == KeyCode.S) {
                        helpOverlay.setVisible(false);
                        scene3d.getCameraController().getPanController().setEnabled(false);
                        scene3d.getCameraController().getOrbitController().setEnabled(false);
                        editing.setEnabled(true);
                        editing.setMode(EditingController.Mode.SELECT);
                    }

                    else if (event.getCode() == KeyCode.D) {
                        helpOverlay.setVisible(false);
                        scene3d.getCameraController().getPanController().setEnabled(false);
                        scene3d.getCameraController().getOrbitController().setEnabled(false);
                        editing.setEnabled(true);
                        editing.setMode(EditingController.Mode.DELETE);
                    }
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
    public static void main(String[] args) {
        launch();
    }
}

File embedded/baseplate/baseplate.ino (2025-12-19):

#include "communication.h"
#include <IRremote.h>

#define NB_DISPENSORS 8
#define IR_LED 21

struct Dispensor {
  int digitalPin;
  int analogPin;
  int status;
};

static Dispensor listDisp[NB_DISPENSORS] = {
  {35, 15, NOT_CONNECTED},
  {42, 16, NOT_CONNECTED},
  {41, 17, NOT_CONNECTED},
  {40, 8, NOT_CONNECTED},
  {36, 7, NOT_CONNECTED},
  {37, 6, NOT_CONNECTED},
  {38, 5, NOT_CONNECTED},
  {39, 4, NOT_CONNECTED}
};

void setup() {
  Serial.begin(9600);

  setupEventTask();

  pinMode(IR_LED, OUTPUT);

  IrSender.begin(IR_LED, ENABLE_LED_FEEDBACK);
  IrSender.enableIROut(38);

  for (int i = 0; i < 8; i++) {
    pinMode(listDisp[i].digitalPin, INPUT_PULLUP);
  }
}

void loop() {
  checkDispensors();
}

int smoothAnalogRead (int pin) {
  long total = 0;
  for (int i= 0; i < 256; i++) {
    total += analogRead(pin);
  }
  return total / 256;
}

DispensorStatus smoothIRRead (int pin) {
  while (1) {
    int nb_pass = 0;
    for(int i = 0; i < 20; i++) {
      uint16_t rawSignal[] = {1000};
      IrSender.sendRaw(rawSignal, 1, 38);
      if (digitalRead(pin) == LOW) {
        nb_pass++;
      }
    }

    if (nb_pass > 5) {
      return PASS;
    } else if (nb_pass == 0) {
      return BLOCKED;
    }
  }
}

void checkDispensors() {

  for (int i = 0; i < 8; i++) {
    int analogValue = smoothAnalogRead(listDisp[i].analogPin);
    DispensorStatus status = smoothIRRead(listDisp[i].digitalPin);

    if (analogValue < 4000 && listDisp[i].status == NOT_CONNECTED) {
      delay(2000);
      analogValue = smoothAnalogRead(listDisp[i].analogPin);
      if (analogValue > 4000) {
        continue;
      }

      // Add dispensor
      putEvent( createDispensorEvent(i, analogValue) );
      listDisp[i].status = status;
      //putEvent( setStatusEvent(i, FULL) );
    } else if (analogValue >= 4000 && listDisp[i].status != NOT_CONNECTED) {
      // Remove dispensor
      putEvent( removeDispensorEvent(i) );
      listDisp[i].status = NOT_CONNECTED;
    }

    /*
    if (status != listDisp[i].status && analogValue < 4000) {
      // Update status
      listDisp[i].status = status;
      putEvent( setStatusEvent(i, status) );
    }
    */
  }
}

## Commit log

2025-10-19 added circuit diagram
2025-10-23 implemented basic stl loading
2025-10-29 implemented stl loading to mesh
2025-11-04 dev-render: added liblxfml and modal forms
    [colors.csv]
2025-11-11 object-loader tests
    [Cube.stl]
2025-11-11 dev-render: added lego assembly rendering
2025-11-11 slicer can now take multiple layers and prints the putput as an image
2025-11-12 dev-render: fixed assembly and lxfml reader for new system
    [Main.java]
2025-11-19 embedded: added lgcode reader for arduino
2025-11-25 made stl loader more robust by shifting and rescaling input coordinates
2025-11-25 full pipeline done from stl to lego construction
2025-11-26 corrected plate size
2025-11-27 main: fixed y axis
    [mklego.ino, physics.cpp, physics.h]
2025-12-02 uploaded testing stl files
    [Bunny-LowPoly.stl, Cube.stl, LPcatBP.stl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]
2025-12-02 feat: Add wiggle before placing a lego
    Add the wiggle referential for it's unique z axis origin.
    Add a wiggle method make the nozzle move as star before placing a lego.
    Call the wiggle in the mklego placing sequence.
2025-12-03 main: added rotateNozzle
    rotateNozzle rotates the nozzle with absolute rotation instead of left right relative movement
2025-12-03 feat: Implement conversion from command to actions
    Add in mklego.ino the functionality to convert received commands
    into specific actions for the printer.
    This includes the Rotate, Move, Drop actions and scaffold of Grab action.
2025-12-03 add big rabbit
    [Bunny-LowPoly-Big.stl]
2025-12-10 Refactor nozzle and movement control
    - Reworked GRAB/MOVE/DROP logic:
    • ensure dispenser height safety (max(z,2))
    • correct dispenser X offset based on brick size
    • added debugging prints for current operation
    - Added wiggle radius to Referential and configurable top/bottom pos
    • updated all referentials with new coords and radius
    • replaced fixed WIGGLE_RADIUS with per-referential values
    - Improved nozzle rotation handling:
    • calibrateR() now accepts rotation argument
    • keep currentRotation state and reapply after nozzleUp()
    • simplified rotateNozzle() using calibrateR()
    - Movement improvements:
    • ensure plate and dispenser clearance before motion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
    [mklego.ino, physics.cpp, physics.h]
2025-12-10 small bug fix
    disable completely editing mode instead of using a enumaration
    [Main.java]
2025-12-10 Dev slicer (#67)
    * ortools for slicer-base and README with run command
    * slicer 2d works, should work in 3d too
    * dev-render: updated main
    * object-loader tests
    * dev-render: added lego assembly rendering
    * main can now take grayscale images to test slicer
    * slicer can now take multiple layers and prints the putput as an image
    * some optimizations and fixes
    * added lego visualisation scaffold
    * dev-render: fixed assembly and lxfml reader for new system
    * dev-render: finished import project form
    * dev-render: added serialization of liblgcode
    * dev-render: finished liblgcode
    * made stl loader more robust by shifting and rescaling input coordinates
    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
    [Bunny-LowPoly-Big.stl, Bunny-LowPoly.stl, Cube.stl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]
2025-12-10 feat(mklego): add basic dispenser management module
    - Introduce dispenser.h and dispenser.cpp for managing LEGO dispensers.
    - Define dispenser struct with position, width, empty state, and brick type.
    - Implement dd_dispenser() to register new dispensers with position validation.
    - Implement get_dispenser() and get_dispensers_it() for dispenser retrieval.
    - Track occupied positions to prevent overlapping dispensers.
2025-12-10 Add melody data
    Add melody definitions (Mario, Star Wars, Pirates of the Caribbean)
    Add pitch frequency table (pitches.h) for sound playback
    Details:
    Adds PROGMEM note arrays, duration arrays, and lengths.
    Adds associated header with extern declarations.
    Introduces standard NOTE_* definitions used by melodies.
2025-12-10 it has the handle functions and also i added in the setup Serial.begin(9600) in case we need it but for now i don't use it anymore and also i call reset_lgcode() as the old code we tested with the ha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
    [mklego.ino]
2025-12-10 editing bug fixes and help panel
    the preview brick in add mode follows correctly the mouse even when moving the camera
    highlighting a piece does not remove color of the whole assembly anymore
    press H do display a help panel witht the keyboard layout
    [Main.java]
2025-12-14 Import Mk-Lego nozzle and dispenser 3D Models
    Add the the 3D models (Fusion 360, STL and DXF files) for the Mk-Lego
    nozzle and dispenser designs.
    [Dispensors_Mk-Lego.f3d, MDF_fixed_holder.dxf, MDF_left_wall.dxf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]
2025-12-14 Remove accidentaly added file
    [diff.txt]
2025-12-15 README: removed useless explanations
    Removed detailed sections about the Power Supply Unit, microcontrollers, dispenser modules, analog signal conditioning, communication, and nozzle servomotor from the README.
2025-12-15 typo in resources dir name
    [Dispensors_Mk-Lego.f3d, MDF_fixed_holder.dxf, MDF_left_wall.dxf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]
2025-12-15 added color and size palette, and option to hide support
    removed button based color and size change
2025-12-16 Implement dispenser UI and integration with print workflow
    - Added dispenser setup UI, including menus for showing dispenser positions and missing dispensers
    - Hardcoded bricks array replaced with zero-initialized array for dynamic detection
    - Added functions to display brick info and check legal placements on LCD
    - Updated runLGCodeFromSD to use dispenser positions when placing bricks
    - Modified dispenser API to accept pointers to bricks for lookup
    - Added dispenser state tracking to handle missing, found, and placement scenarios
    - Updated handleEncoder and handleButtons for dispenser navigation
    - Added visual indicators on LCD for placed, hollow, and currently placing blocks
    [ui.cpp, ui.h]
2025-12-16 Refactor print engine with improved operation handling
2025-12-16 Update print statement from 'Hello' to 'Goodbye'
2025-12-16 solved non-printing problem and solved small icon problem
    [ui.cpp]
2025-12-16 Revert "Merge branch 'main' of https://github.com/epfl-cs358/2025fa-mklego"
    This reverts commit abf04e43cf2a47c96ac8d24a306506b3cf9db9b3, reversing
    changes made to 5cf45c6113a11852487b7fd6c0b3477857532dfd.
    [ui.cpp]
2025-12-16 export as lgcode and LG fixed
    [Main.java]
2025-12-16 Number of positions corrected and for the moment use size to chose dispenser
    [ui.cpp]
2025-12-17 Add more resources for 3D Models
    [BasePlate_Mk-Lego.f3d, BasePlate_Mk-Lego_Borders.stl, Dispensers_Mk-Lego.f3d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]
2025-12-17 Add building tutorial and component assembly details
    Updated the README to include a building tutorial with detailed steps and materials for assembling components like the nozzle, baseplate, and dispensers.
2025-12-17 Revise building tutorial and assembly instructions
    Updated the README to improve clarity and structure of the building tutorial, including detailed assembly steps and material lists.
2025-12-17 Add elec boxes
    [MDF_main_electrical_box.dxf, MDF_sub_electrical_box.dxf]
2025-12-17 added micro switch documentation
2025-12-17 typo in readme
    fixed formatting in the materials list.
2025-12-18 Refactor UI, print and dispenser
2025-12-19 added delay in resistor reading
2025-12-19 Update main controller from STM32 to Arduino Mega
2025-12-19 export button as menu for lg and lgocode
2025-12-19 Update assembly instructions in README
    Added important notes about springs and grabber installation.
2025-12-19 Clarify assembly process with resource file locations
    Updated assembly instructions to include file locations for resources.
